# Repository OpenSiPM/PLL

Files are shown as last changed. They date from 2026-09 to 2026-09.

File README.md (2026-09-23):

## Overview

Resonant scanning is essential for high-speed and *in vivo* laser scanning microscopy. However, resonant scanners are susceptible to jitter due to a mismatch between the mirror's mechanical oscillation and the data acquisition system's pixel sampling clock. If the digitizer samples at a fixed rate, the pixels on one line land in slightly different positions than on the next and the raw data appears shifted from line to line.

Our solution is to generate the digitizer sample clock **from the resonant scanner's own sync signal** using a PLL. Every line is then sampled at the same scanner phase, so the pixel grid follows the scanner rather than drifting against it. The method runs in real time, is entirely electrical and requires no software changes, so it can be easily incorporated into most existing microscopy systems. 

This approach is described and validated in:

> Ching-Roa VD, Huang CZ, Giacomelli MG. **Suppression of Subpixel Jitter in Resonant Scanning Systems With Phase-locked Sampling.** *IEEE Transactions on Medical Imaging* 43(6):2159–2168, 2024. [doi:10.1109/TMI.2024.3358191](https://doi.org/10.1109/TMI.2024.3358191) · [PubMed 38265914](https://pubmed.ncbi.nlm.nih.gov/38265914/)

The repository is organized into separate folders: PLL_AD9544 contains the KiCAD design files for the board, Configuration Files contains the AD9544 register configurations and a script to convert them into EEPROM images, and EEPROM_writer together with PLL_EEPROM_upload.m are used to program the configuration onto the board.

## AD9544 PLL Board 
This PCB receives the resonant scanner sync signal, locks to it using an Analog Devices AD9544 clock generator, and outputs a phase-locked sample clock for the digitizer and a line trigger. The AD9544 is referenced to a 52 MHz crystal, and its configuration is stored in a 24AA16 I2C EEPROM, which the AD9544 loads automatically at power-up. A SAMD21 microcontroller receives commands over USB and is used to program the EEPROM. Power is supplied over USB and regulated down to 3.3 V and 1.8 V, and a PLL LOCK LED indicates when the PLL has locked to the reference.

- **J1 (USB):** power and EEPROM programming
- **J3 (output):** phase-locked pixel sample clock to the digitizer
- **J4 (output):** line trigger at the scanner frequency
- **J5 (input):** resonant scanner sync signal (8 kHz or 12 kHz)

See: [PLL_AD9544](PLL_AD9544). [Bill of materials](https://htmlpreview.github.io/?https://github.com/tikagergaia/PLL/blob/main/PLL_AD9544/ibom.html)

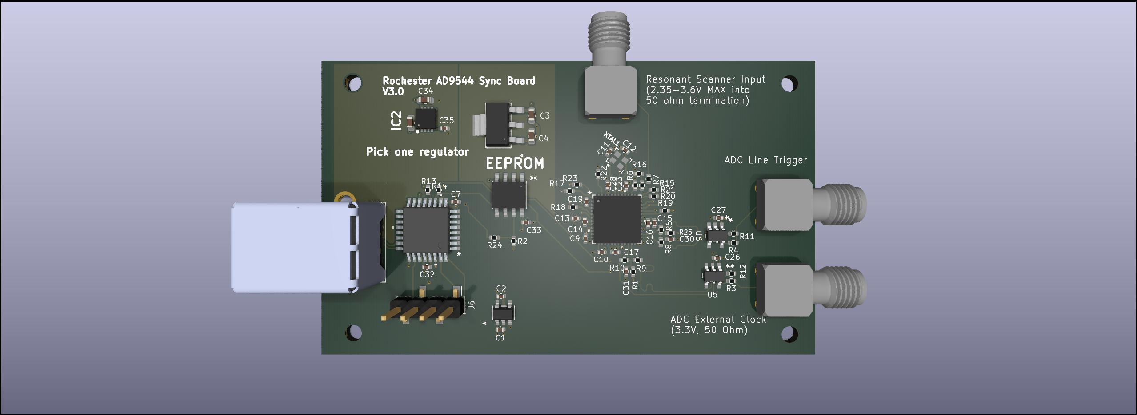
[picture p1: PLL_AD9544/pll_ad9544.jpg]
PLL Board


## Configuration files
1. The AD9544 is configured through its registers, which are designed using the [Analysis|Control|Evaluation(ACE) Software Version 1.10.2671.1118](https://swdownloads.analog.com/ACE/ACEInstall_1.10.2671.1118.exe). *Do not update it to newer versions as they are not tested with the AD9544 plug-in module.* In ACE, set up the reference input, DPLL, output frequencies, and loop bandwidth. The ACE session can then be exported as a `.cso` file for the register settings.

   ACE Software

   The PLL LOCK LED is driven by the AD9544's M0 multifunction pin (M-pin), which is set up in ACE as a lock status output:

   LED_config

2. Use the `ad9545_create_eeprom_bin.py` script to generate bin files for EEPROM. Set `fn` in the script to your `.cso` file and run it from inside the `Configuration Files` folder (it needs `bitarray.py` and `defaults.txt`, which are in the same folder). It writes a `.bin` file with the same name as the `.cso`.

Sample files for 8 kHz and 12 kHz scanners are available in the `Configuration Files` folder (both `.cso` and ready-to-upload `.bin` files are included).

The approach does not depend on the AD9544. Other clock chips (for example, the AD9545) can do the same job. They need their own configuration files and EEPROM image, but the principle stays the same.

## Programming EEPROM
The EEPROM_writer folder contains the Arduino sketch for the SAMD21 microcontroller, which requires the [I2C_eeprom](https://github.com/RobTillaart/I2C_EEPROM) library. On startup, the sketch reports the EEPROM size and the scanner frequency currently stored in it.

To program a configuration onto the board:

1. Upload `EEPROM_writer/EEPROM_writer.ino` to the SAMD21 using the Arduino IDE.
2. Open `PLL_EEPROM_upload.m` in MATLAB, set the path to your `.bin` file (e.g. `Configuration Files/12kHz_LED.bin`) and the board's COM port (`'COMX'`), and run the script. It sends the `program` command followed by the 1280-byte image, reads the EEPROM contents back and compares checksums. "Checksum of file matches uploaded data." means the upload succeeded.
3. Power-cycle the board. The AD9544 loads its configuration from the EEPROM, and the PLL LOCK LED lights once a valid reference is connected.

## Ordering boards

Go to https://jlcpcb.com, https://www.seeedstudio.com/fusion_pcb.html or the service of your choice, upload the Gerber files, and pay.

Gerber files can be generated from KiCAD using 'File -> Plot' or using the JLCPCB Fabrication Toolkit plugin (settings are included in `PLL_AD9544/fabrication-toolkit-options.json`).

## Board assembly

The easiest way to assemble this board is using solder paste and a reflow oven or hotplate. The AD9544 comes in a 48-lead LFCSP package with an exposed ground pad, and most of the passives are 0402, so reflow is strongly recommended over hand soldering. If you're going to make several boards, paying for assembly of the passive and common components might be worthwhile.

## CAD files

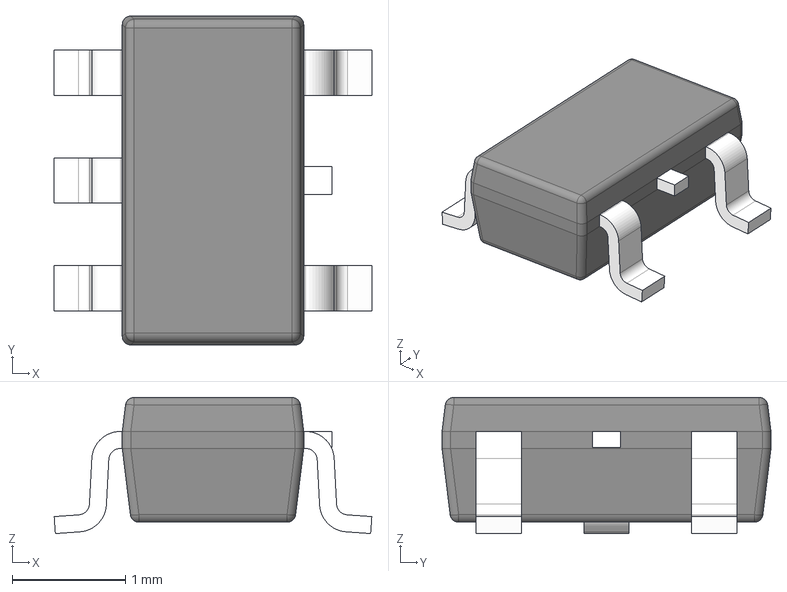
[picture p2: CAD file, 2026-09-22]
PLL_AD9544/step/DBV0005A.stp
2.80 x 2.90 x 1.20 mm
BODY-SOT
LEAD-SOT x 5
LEAD-DUMMY

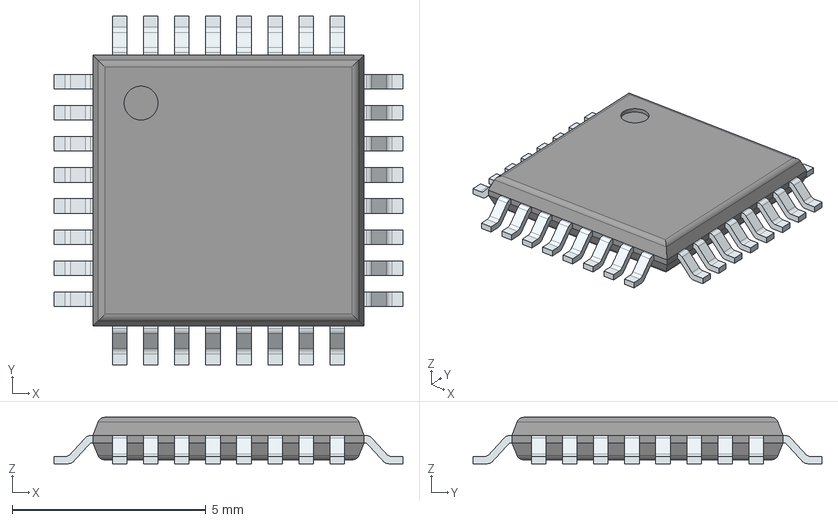
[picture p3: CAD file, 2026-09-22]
PLL_AD9544/step/ATSAMD21E18A-AFT.stp
9.00 x 9.00 x 1.20 mm
PinsArrayLR
PinsArrayTB

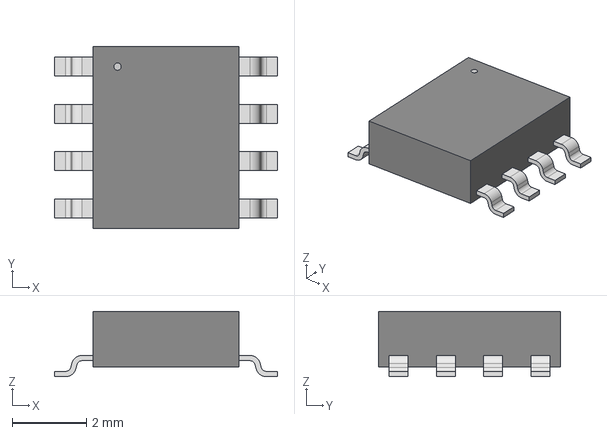
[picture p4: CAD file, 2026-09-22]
PLL_AD9544/step/SOIC8-N_MC_MCH.step
5.99 x 4.90 x 1.75 mm

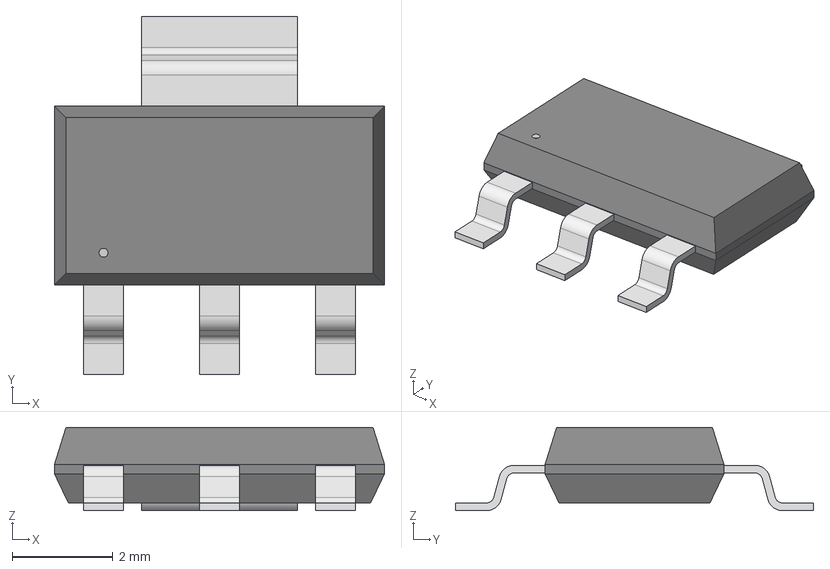
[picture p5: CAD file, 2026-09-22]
PLL_AD9544/step/SOT-223_DIO.step
6.55 x 7.10 x 1.65 mm

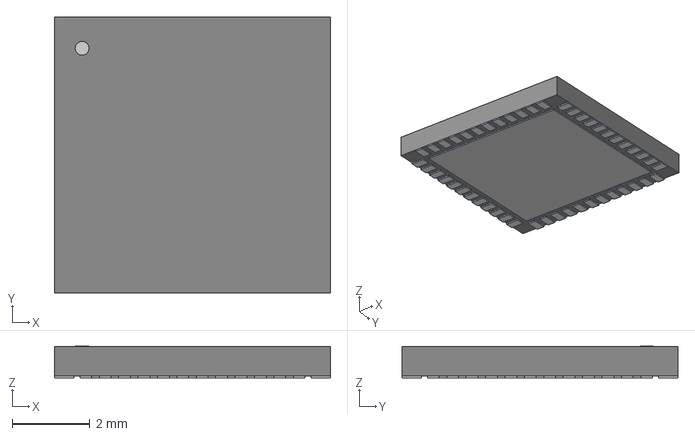
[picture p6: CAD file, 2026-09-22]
PLL_AD9544/step/CP-48-13_ADI.step
7.11 x 7.11 x 0.815 mm

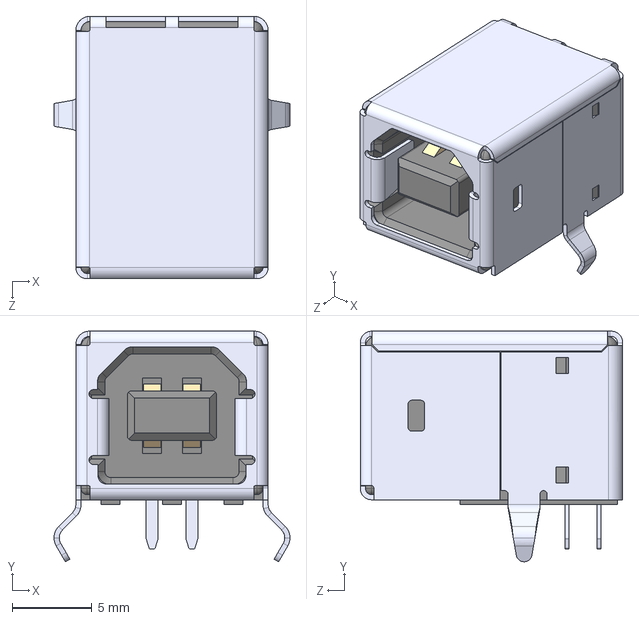
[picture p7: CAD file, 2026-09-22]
PLL_AD9544/step/USB-B1HSB6.step
14.8 x 14.5 x 16.5 mm

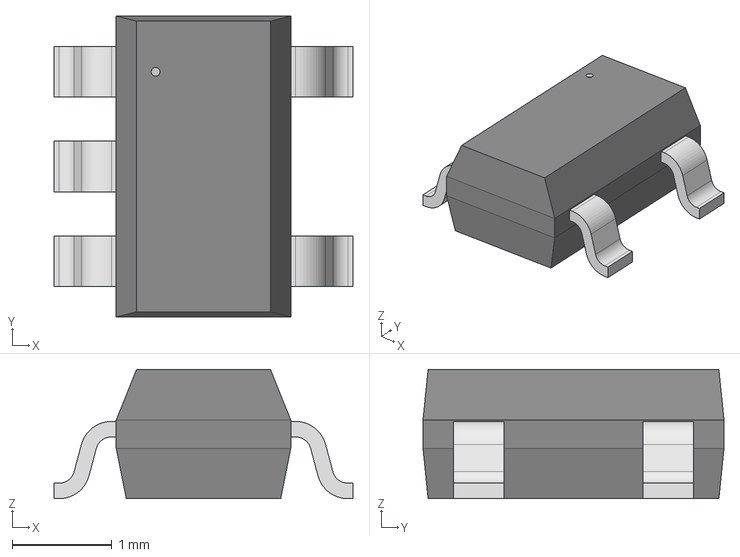
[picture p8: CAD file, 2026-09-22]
PLL_AD9544/step/SOT-23-5_M5_MCH.step
3.00 x 3.02 x 1.30 mm

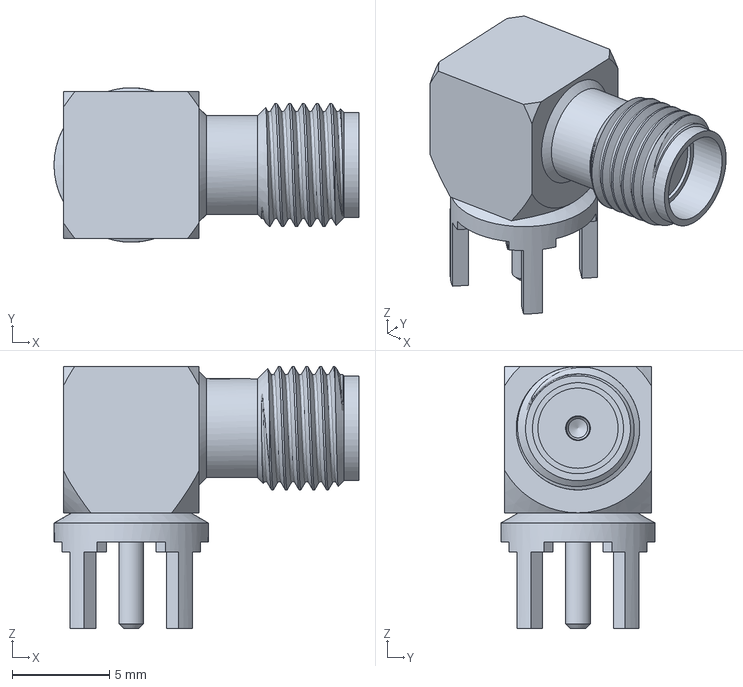
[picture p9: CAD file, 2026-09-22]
PLL_AD9544/step/142-0701-301.stp
15.6 x 7.92 x 13.5 mm

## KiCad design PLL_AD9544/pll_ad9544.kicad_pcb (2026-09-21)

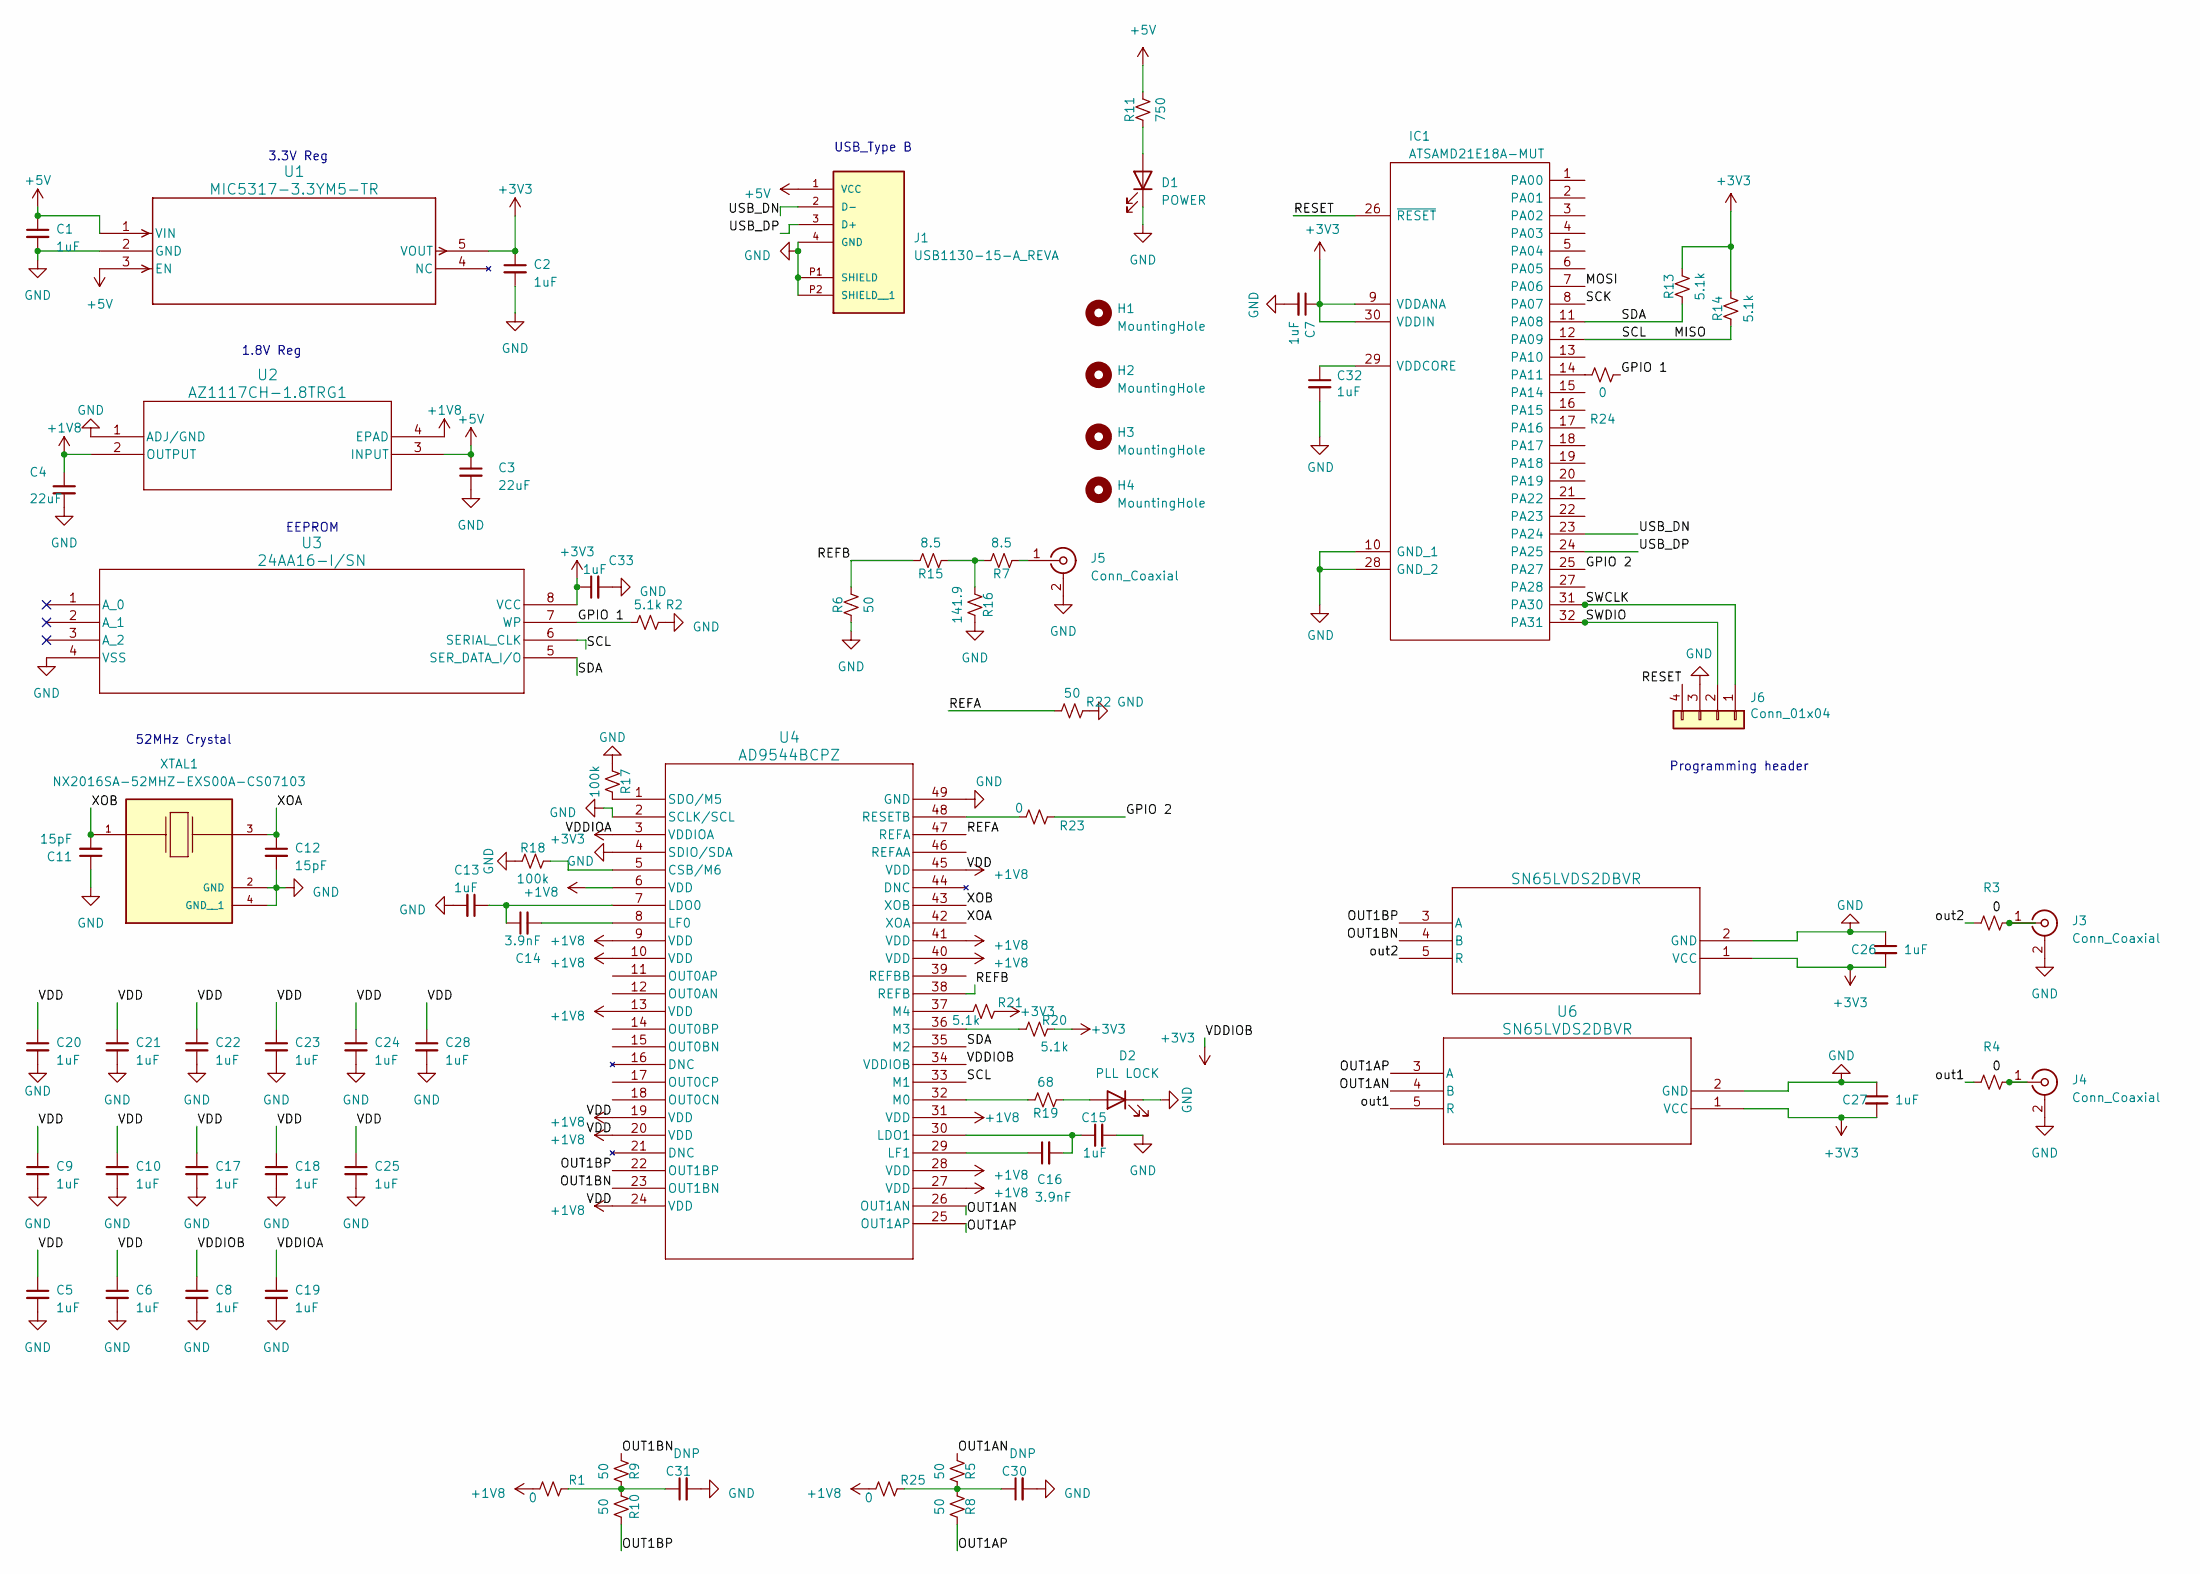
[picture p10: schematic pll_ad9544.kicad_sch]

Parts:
C1, C2, C5, C6, C7, C8, C9, C10, C13, C15, C17, C18, C19, C20, C21, C22, C23, C24, C25, C26, C27, C28, C32, C33: 1uF; C_0402_1005Metric
C3, C4: 22uF; C_0603_1608Metric
C11, C12: 15pF; C_0402_1005Metric
C14, C16: 3.9nF; C_0402_1005Metric
C30, C31: DNP; C_0402_1005Metric
D1: POWER; LED_0603_1608Metric
D2: PLL LOCK; LED_0603_1608Metric
H1, H2, H3, H4: MountingHole; MountingHole_2.5mm
IC1: ATSAMD21E18A-MUT; TQFP32_MC_MCH; Manufacturer_Part_Number ATSAMD21E18A-AFT
J1: USB1130-15-A_REVA; OST_USB-B1HSB6; PARTREV A
J3, J4, J5: Conn_Coaxial; SMA_Amphenol_901-144_Vertical
J6: Conn_01x04; PinHeader_1x04_P2.54mm_Vertical_SMD_Pin1Left
R1, R23, R24, R25: 0; R_0402_1005Metric
R2, R13, R14, R20, R21: 5.1k; R_0402_1005Metric
R3, R4: R_Small_US; R_0402_1005Metric
R5, R6, R8, R9, R10, R22: 50; R_0402_1005Metric
R7, R15: 8.5; R_0402_1005Metric
R11: 750; R_0402_1005Metric
R16: 141.9; R_0402_1005Metric
R17, R18: 100k; R_0402_1005Metric
R19: 68; R_0402_1005Metric
U1: MIC5317-3.3YM5-TR; SOT-23-5_M5_MCH
U2: AZ1117CH-1.8TRG1; SOT-223_DIO
U3: 24AA16-I/SN; SOIC8-N_MC_MCH
U4: AD9544BCPZ; CP-48-13_ADI
U5, U6: SN65LVDS2DBVR; DBV5
XTAL1: NX2016SA-52MHZ-EXS00A-CS07103; OSCCC200X160X50N; PARTREV N/A

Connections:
+1V8: C4.1, C5.1, C6.1, C9.1, C10.1, C17.1, C18.1, C20.1, C21.1, C22.1, C23.1, C24.1, C25.1, C28.1, R1.2, R25.2, U2.2 (OUTPUT), U2.4 (EPAD), U4.6 (VDD), U4.9 (VDD), U4.10 (VDD), U4.13 (VDD), U4.19 (VDD), U4.20 (VDD), U4.24 (VDD), U4.27 (VDD), U4.28 (VDD), U4.31 (VDD), U4.40 (VDD), U4.41 (VDD), U4.45 (VDD)
+3V3: C2.1, C7.1, C8.1, C19.1, C26.2, C27.2, C33.1, IC1.9 (VDDANA), IC1.30 (VDDIN), R13.1, R14.1, R20.1, R21.1, U1.5 (VOUT), U3.8 (VCC), U4.3 (VDDIOA), U4.34 (VDDIOB), U5.1 (VCC), U6.1 (VCC)
+5V: C1.1, C3.1, J1.1 (VCC), R11.1, U1.1 (VIN), U1.3 (EN), U2.3 (INPUT)
/GPIO 1: R2.1, R24.1, U3.7 (WP)
/GPIO 2: IC1.25 (PA27), R23.1
/MISO: IC1.12 (PA09), R14.2, U3.6 (SERIAL_CLK), U4.33 (M1)
/MOSI: IC1.7 (PA06)
/OUT1AN: R5.2, U4.26 (OUT1AN), U6.4 (B)
/OUT1AP: R8.1, U4.25 (OUT1AP), U6.3 (A)
/OUT1BN: R9.2, U4.23 (OUT1BN), U5.4 (B)
/OUT1BP: R10.1, U4.22 (OUT1BP), U5.3 (A)
/REFA: R22.2, U4.47 (REFA)
/REFB: R6.1, R15.1, U4.38 (REFB)
/RESET: IC1.26 (~RESET), J6.4
/SCK: IC1.8 (PA07)
/SDA: IC1.11 (PA08), R13.2, U3.5 (SER_DATA_I/O), U4.35 (M2)
/SWCLK: IC1.31 (PA30), J6.1
/SWDIO: IC1.32 (PA31), J6.2
/USB_DN: IC1.23 (PA24), J1.2 (D-)
/USB_DP: IC1.24 (PA25), J1.3 (D+)
/XOA: C12.1, U4.42 (XOA), XTAL1.3
/XOB: C11.2, U4.43 (XOB), XTAL1.1
/out1: R4.2, U6.5 (R)
/out2: R3.2, U5.5 (R)
GND: C1.2, C2.2, C3.2, C4.2, C5.2, C6.2, C7.2, C8.2, C9.2, C10.2, C11.1, C12.2, C13.2, C15.2, C17.2, C18.2, C19.2, C20.2, C21.2, C22.2, C23.2, C24.2, C25.2, C26.1, C27.1, C28.2, C30.2, C31.2, C32.2, C33.2, D1.1 (K), D2.1 (K), IC1.10 (GND_1), IC1.28 (GND_2), IC1.33 (EP), J1.4 (GND), J1.P1 (SHIELD), J1.P2 (SHIELD__1), J3.2 (Ext), J4.2 (Ext), J5.2 (Ext), J6.3, R2.2, R6.2, R16.1, R17.2, R18.2, R22.1, U1.2 (GND), U2.1 (ADJ/GND), U3.4 (VSS), U4.2 (SCLK/SCL), U4.4 (SDIO/SDA), U4.49 (GND), U5.2 (GND), U6.2 (GND), XTAL1.2 (GND), XTAL1.4 (GND__1); also elsewhere on the board
unnamed: C30.1, R5.1, R8.2, R25.1
unnamed: C31.1, R1.1, R9.1, R10.2
unnamed: D1.2 (A), R11.2
unnamed: D2.2 (A), R19.2
unnamed: IC1.14 (PA11), R24.2
unnamed: C32.1, IC1.29 (VDDCORE)
unnamed: J3.1 (In), R3.1
unnamed: J4.1 (In), R4.1
unnamed: J5.1 (In), R7.2
unnamed: R7.1, R15.2, R16.2
unnamed: R18.1, U4.5 (CSB/M6)
unnamed: C13.1, C14.1, U4.7 (LDO0)
unnamed: C15.1, C16.2, U4.30 (LDO1)
unnamed: C14.2, U4.8 (LF0)
unnamed: C16.1, U4.29 (LF1)
unnamed: R19.1, U4.32 (M0)
unnamed: R20.2, U4.36 (M3)
unnamed: R21.2, U4.37 (M4)
unnamed: R23.2, U4.48 (RESETB)
unnamed: R17.1, U4.1 (SDO/M5)

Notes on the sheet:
EEPROM
USB_Type B
Programming header
1.8V Reg
3.3V Reg
52MHz Crystal

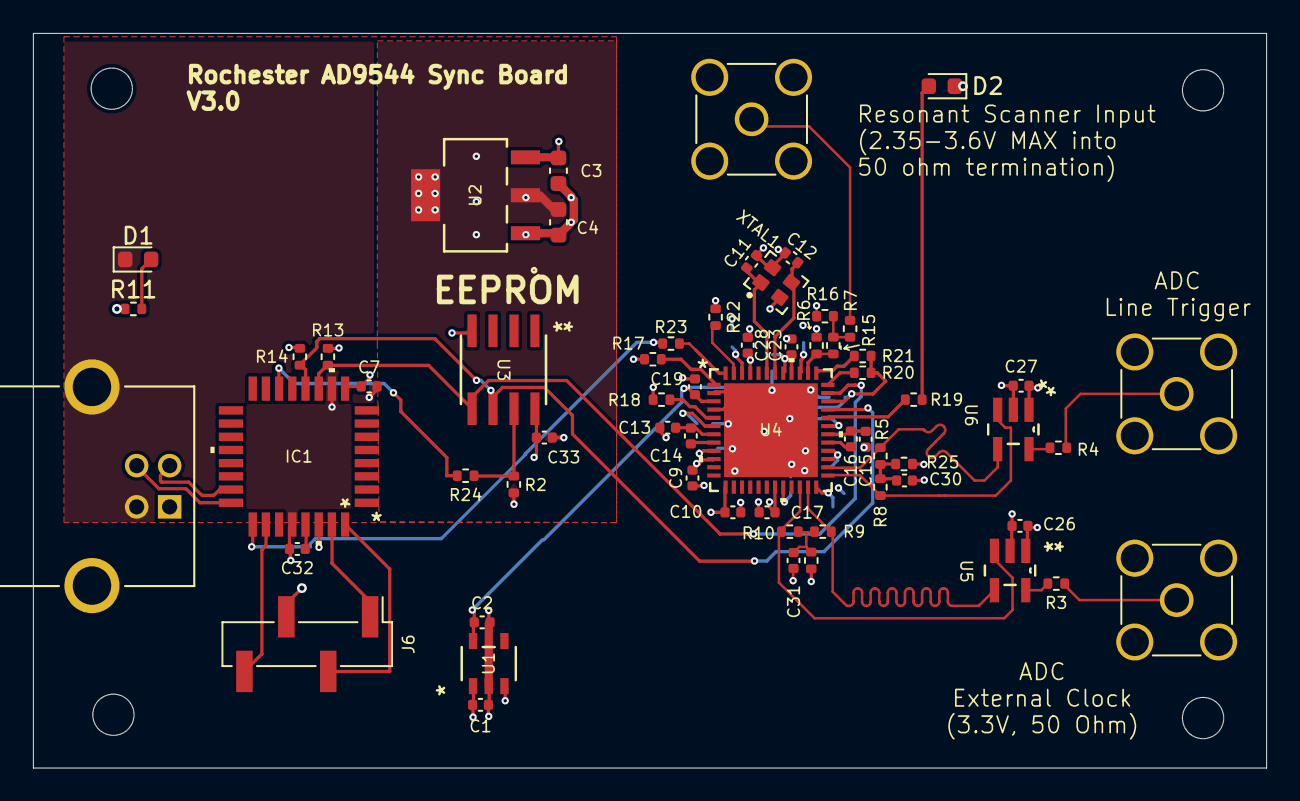
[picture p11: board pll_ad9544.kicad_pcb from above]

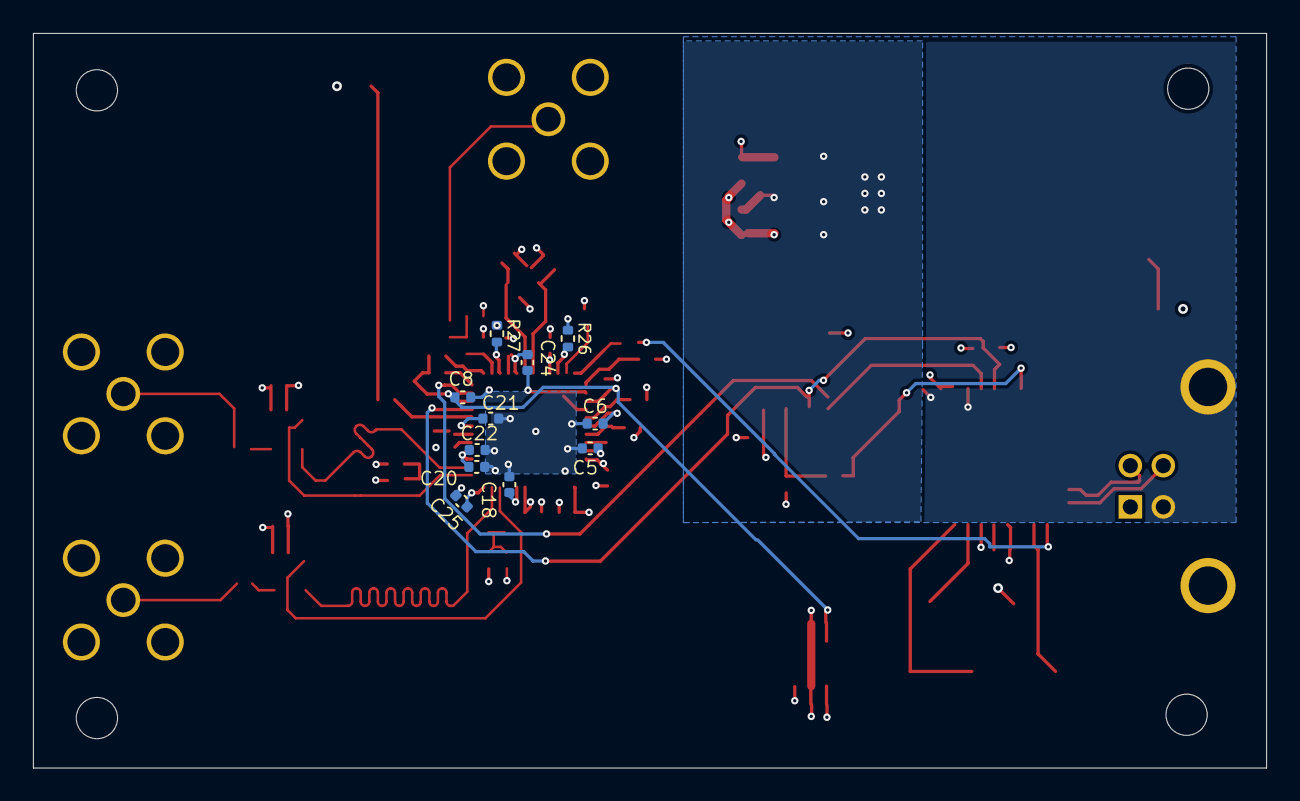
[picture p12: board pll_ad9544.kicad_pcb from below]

Board: 4 copper layers, 74.8 x 44.5 mm, 77 parts (11 on the bottom side), 43 nets.

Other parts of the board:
R26, R27: 50; R_0402_1005Metric

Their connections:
GND: R26.1, R27.1; also elsewhere on the board

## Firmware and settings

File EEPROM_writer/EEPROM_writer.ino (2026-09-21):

#include "Wire.h"
#include "I2C_eeprom.h"

// updated November 13, 2025

I2C_eeprom ee(0x50, I2C_DEVICESIZE_24LC16);  // Define eeprom model

char msgbuf[1280];  // Create message buffer

uint32_t start, diff = 0;

void setup() {

  Serial.begin(115200);  //Open Serial library
  while (!Serial);    //Wait for Serial port to connect
  Serial.println(__FILE__);  //Print file location
  //Print eeprom version
  Serial.print("I2C_EEPROM_VERSION: ");
  Serial.println(I2C_EEPROM_VERSION);

  Wire.begin();  //Open Wire library

  ee.begin();  //Initalize eeprom

  //Determine connection status
  if (!ee.isConnected()) {
    Serial.println("ERROR: Can't find eeprom\nstopped...");
    while (1);
  }
  Serial.print("isConnected:\t");
  Serial.println(ee.isConnected());

  //Determine size of eeprom
  Serial.println("\nTEST: determine size");
  start = micros();
  uint32_t size = ee.determineSize(true);
  diff = micros() - start;
  //Print time to determine size
  Serial.print("TIME: ");
  Serial.println(diff);
  if (size > 0) {
    Serial.print("SIZE: ");  //Print size
    Serial.print(size);
    Serial.println(" Bytes");  //Print number of bytes
  } else if (size == 0) {
    Serial.println("WARNING: Can't determine eeprom size");
  } else {
    Serial.println("ERROR: Can't find eeprom\nstopped...");
    while (1)
      ;
  }

  // Determine the frequency
  /* read in the refb clock period, which is the number of attoseconds (1E-18) per
     resonant scanner cycle.  This is a 6 byte number, but the last two bytes are
     irrelevant at the kHz frequency resolution.
  */
  uint32_t period;
  ee.readBlock(0x9E, (uint8_t *)&period, 4);

  //period is now in 65536 * attoseconds, convert to microseconds
  // uint8_t period_us = period *  6.5536e-08; // 65536/1E+12
  float period_us = period * 6.5536e-08;  // 65536/1E+12
  Serial.print("PERIOD: ");
  Serial.print(period_us);
  Serial.print(" us\n");

  // calculate the frequency in kHz
  float freq = 1000.0 / period_us;
  Serial.print("FREQ: ");
  Serial.print(freq);
  Serial.print(" kHz");
}

void loop() {

  if (Serial.available())
    Serial.read();
  {
    while (!Serial.available()) {}

    //check for command and abort loop if a valid one is not received

    String cmd = Serial.readStringUntil('\n');
    cmd.trim();
    char *str = (char *)cmd.c_str();

    if (strcmp(str, "program") != 0) {
      Serial.print("Invalid command:");
      Serial.print(str);
      Serial.print("!");
      return;
    }

    else { //so we don't keep erasing the EEPROM
      int bytes = 0;
      char romBuf[1280];                       //creates character array size of eeprom
      bytes = Serial.readBytes(romBuf, 1280);  //reads the rom into the array


      if (bytes < 1280)
        return;

      ee.writeBlock(0, (uint8_t *)romBuf, 1280);  //writes all bytes into eeprom
      // verify written correctly,into msg buffer
      char readBuffer[1280];
      ee.readBlock(0, (uint8_t *)readBuffer, 1280);
      for (size_t i = 0; i < 1280; i++) {
        sprintf(msgbuf, "%d ", readBuffer[i]);
        Serial.write(msgbuf);  //sends value of bytes to serial monitor
      }
    }
  }
}

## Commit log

2026-09-21 Add initial README structure for AD9544 PLL Board
2026-09-21 Add image for AD9544 PLL Board in README
2026-09-21 Add ACE and LED configuration images to README
    Added images for ACE Software and LED configuration to README.
2026-09-22 KiCAD Files
    [142-0701-301.stp, ATSAMD21E18A-AFT.stp, CP-48-13_ADI.step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]
